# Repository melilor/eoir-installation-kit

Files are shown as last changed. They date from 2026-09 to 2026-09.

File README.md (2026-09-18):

# EO/IR Payload Installation Kit — Model-Based System Engineering Study



A model-based system engineering study of the **installation kit** that lets a light
helicopter (CS-27 class) or a tactical UAV carry a stabilised electro-optical / infrared
payload: the structural attachment, the electrical and avionic interfaces, the weight and
balance impact, the preservation of the payload field of view, and the compliance data an
EASA Part 21 Design Organisation Approval (DOA) holder works with.

The study is built as a **model**, not as a folder of documents. Requirements live in a
[Doorstop](https://doorstop.readthedocs.io) document, the architecture lives in YAML, every
requirement points at its source, and a validator in this repository fails the build when a
requirement has no source, no owning architecture element or no verification case — or when
a verification claims evidence that is not in the repository. The map of the whole study is
in [`docs/overview.md`](docs/overview.md).

```
$ python -m tools.traceability check
checked 38 requirements, 28 verification cases, 12 components: 0 errors, 12 warnings
```

The warnings are the discipline working: `ASM-OPEN` flags the evidence that rests on a
declared assumption that is still open (the payload data, the platform data, the harness
installation rules, the payload video link). They stay until the assumption is closed or the
limitation is accepted in writing.

## What this is / what this is not

| This repository is | This repository is not |
| --- | --- |
| a system engineering study of an installation kit | a design of the EO/IR sensor |
| a requirements, architecture and verification model with enforced traceability | a certification dossier |
| an application of CS-27, RTCA DO-160G and EASA Part 21 as a frame | an application of DO-178C, DO-331 or DO-254 |
| declared assumptions, marked as assumptions | measurements, test results or supplier data |
| a first published slice, with its gaps listed | a finished project |

The payload, the platform and the environment are **declared assumptions**, written in
[`model/assumptions.yaml`](model/assumptions.yaml) and referenced by the requirements that
depend on them. An assumption is an input the study needs, not a fact.

## Status

**Revision J — first published slice, 2026-09-18.** 38 requirements, 12 components, 28
verification cases, 15 declared assumptions, 13 documents, 93 layout checks, 16 mass checks, 3
clearance checks, 5 electrical checks, 44 load path checks, 46 qualification plan checks.
**Twenty-three cases are closed** at the level the evidence supports — thirteen `PASS` and ten
`LIMITATION` for what a model cannot demonstrate; the other 5 are `FUTURE` and point at the
ticket that will produce their evidence. The [technical report](docs/report.md) compiles the
study, its 34 classified limitations and the review of the package. The
[traceability matrix](docs/traceability.md) says this case by case, and it is generated from
the model, never written by hand.

## Quick start

```bash
pip install -r requirements.txt

doorstop --no-ref-check --no-level-check      # validate the requirements documents
python -m tools.traceability check            # validate the whole model
python -m tools.traceability report           # regenerate docs/traceability.md
python -m tools.diagram                       # regenerate docs/architecture.md
python -m tools.layout                        # run the layout checks, write evidence/layout/
python -m tools.compliance                    # regenerate docs/compliance-matrix.md
python -m tools.mass                          # run the mass and balance analysis
python -m tools.clearance                     # run the field of view and clearance analysis
python -m tools.power                         # run the electrical power budget and protection check
python -m tools.loads                         # run the load path and strength analysis
python -m tools.qualification                 # regenerate the environmental qualification plan
python -m tools.report                        # regenerate the technical report and run the review
python -m pytest                              # run the test suite
```

## Repository layout

```
model/
  requirements/          SYS001..SYS038 — system requirements (Doorstop)
  verification/          VER001..VER028 — verification cases, linked to their requirements
  architecture/          functions, components, interfaces, external boundary
  interfaces/            declared interface control data (payload, platform)
  assumptions.yaml       declared assumptions and interface data (ASM A-00x)
  evidence.yaml          one record per verification case: method, status, artifact, plan
  layout.yaml            the single source of truth for every dimension of the kit
  mass.yaml              component masses, stations and loadable configurations
  compliance.yaml        change classification and the document register
evidence/
  layout/                generated: checks.json, report.md, layout.svg, layout.dxf
  mass/                  generated: checks.json, report.md
  clearance/             generated: checks.json, report.md, sweep.svg
  power/                 generated: checks.json, report.md
  loads/                 generated: checks.json, report.md
  qualification/         generated: checks.json, report.md
  review/                generated: checks.json, report.md
tools/
  model.py               load the model parts
  rules.py               the validation rules, one identifier per failure
  analysis.py            the result structure shared by the analysis tools
  traceability.py        command line: check, report, report --check
  diagram.py             generate docs/architecture.md from the architecture model
  layout.py              run the layout checks and write the evidence
  mass.py                run the mass and balance analysis and write the evidence
  clearance.py           run the field of view analysis and write the evidence
  power.py               run the electrical analysis and write the evidence
  loads.py               run the load path and strength analysis and write the evidence
  qualification.py       generate the environmental qualification plan and check it
  report.py              generate the technical report and review the package
  compliance.py          generate the compliance matrix and the document register
tests/                   170 tests: one failing model per rule, plus the repository model
docs/
  overview.md            the map of the study: model, numbers, limits, next steps
  architecture.md        generated diagram and allocation tables
  traceability.md        generated matrix: requirement → architecture → verification → evidence
  compliance-matrix.md   generated: classification, compliance matrix, document register
  ica.md                 instructions for continued airworthiness (outline)
  method.md              how the model works and why the tools were chosen
  adr/                   decision records
```

## The model, in one picture

```
requirement (SYS) ──┬──> architecture element (CMP / FCT / IF) ──> allocation
                    │
                    └──> verification case (VER) ──> evidence record (method, status, artifact)
```

The rules that hold this together, each with a stable identifier in
[`tools/rules.py`](tools/rules.py):

| Rule | What it rejects |
| --- | --- |
| `REQ-SOURCE` | a requirement whose source is missing, malformed or an unknown assumption |
| `ARCH-ALLOC` | a requirement that no component owns |
| `ARCH-REQ` | an architecture element with no requirement, or pointing at one that does not exist |
| `ARCH-REALIZES` | a function no component realises, or a component that realises nothing |
| `VER-COVER` | a requirement with no verification case |
| `VER-EVIDENCE` | a verification case without an evidence record |
| `EVIDENCE-ARTIFACT` | a `PASS` or `WARN` claim whose artifact is not in the repository |
| `EVIDENCE-PLAN` | a `FUTURE` case with no ticket attached to it |
| `ASM-OPEN` | evidence produced against a declared assumption that is still open |
| `ASM-FILE` | an assumption pointing at declared interface data that is not in the repository |
| `COMPLIANCE-COVERAGE` | a requirement with no compliance document, or covered by more than one |
| `COMPLIANCE-REF` | a document covering an unknown requirement, an empty register entry, an unknown state or type, a duplicate id |
| `COMPLIANCE-FILE` | a document declared in the register whose file is not in the repository |
| `MASS-COVERAGE` | a component without a declared mass, or a mass entry for an unknown component |
| `CLASSIFICATION` | a change classification without criteria, with an unknown effect, or a major change without an approval route |

## Standards used as the frame

| Reference | Used for |
| --- | --- |
| 14 CFR Part 27 (CS-27 class) — 27.301/27.303/27.305, 27.23, 27.561, 27.1301/27.1309, 27.1316/27.1317, 27.1351–27.1367, 27.1529 | loads, factor of safety, strength, weight and balance, equipment installation, electrical systems, continued airworthiness |
| RTCA DO-160G — Sections 4, 6, 8, 14, 16, 20, 21 | environmental qualification of the installation |
| EASA Part 21 Subpart D (21.A.91/21.A.95/21.A.97) and 21.A.239 | change classification, approval route, design assurance |
| SAE ARP4754A | development process frame |
| ISO/IEC/IEEE 29148 | requirement quality criteria |
| ARINC 429 | payload control interface (declared) |

## Licence

Code: MIT (`LICENSE`). Documentation: CC BY 4.0 (`docs/LICENSE-CC-BY-4.0.md`).

## Author

Anthony Migliore — aerospace engineering graduate, Milan.
[LinkedIn](https://www.linkedin.com/in/miglioreanthony)

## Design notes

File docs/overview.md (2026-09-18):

# Study overview

The map of this repository: what the study is, how the model is built, what is verified and
what is not, and where the work goes next.

## What this study is

A model-based system engineering study of the **installation kit** that lets a light
helicopter (CS-27 class) or a tactical UAV carry a stabilised electro-optical / infrared
payload. The sensor is the input, not the subject: the subject is the structural attachment,
the electrical and avionic interfaces, the weight and balance impact, the preservation of
the field of view, and the compliance data frame an EASA Part 21 Design Organisation
Approval holder works with.

The study is built as a **model**, not as a folder of documents. Requirements live in a
Doorstop document, the architecture and the evidence live in YAML, and a validator in this
repository enforces the whole chain. If a requirement has no source, no owning component or
no verification case, the build is red.

**Status — revision J, 2026-09-18.** 38 requirements, 12 components, 28 verification cases,
15 declared assumptions, 93 layout checks, 16 mass checks, 3 clearance checks, 5 electrical
checks, 44 load path checks, 46 qualification plan checks, 13 documents in the compliance
register, 150 tests, CI green. **Twenty-three verification cases are closed** at the level the
evidence supports — thirteen `PASS` and ten `LIMITATION` for what a model cannot demonstrate;
the other 5 are `FUTURE` and each one names the ticket that will produce its evidence. Twelve
`ASM-OPEN` warnings flag the evidence that rests on a declared assumption that is still open. That is the honest state of the study and it is visible in
[the traceability matrix](traceability.md) and in the
[compliance matrix](compliance-matrix.md).

## The model, end to end

Every arrow below is a rule in `tools/rules.py`, checked in CI:

```
      ASSUMPTION A-00x                STANDARD (STD …)
      declared input                  cited clause
              \                        /
               \                      /
                ▼                    ▼
    ┌────────────────────────────────────────────────────────┐
    │ REQUIREMENT   SYS001 … SYS038                          │  REQ-SOURCE
    │ text + source + verifiable acceptance criterion        │  REQ-TEXT
    └───────────────────────┬────────────────────────────────┘
                            │
                            │  ARCH-ALLOC · ARCH-REQ · ARCH-REALIZES · ARCH-IFACE
                            ▼
    ┌────────────────────────────────────────────────────────┐
    │ ARCHITECTURE                                           │
    │ 9 functions (FCT) · 12 components (CMP)                │
    │ 9 interfaces (IF) · 6 external entities (EXT)          │
    └───────────────────────┬────────────────────────────────┘
                            │
                            │  VER-COVER · VER-LINK
                            ▼
    ┌────────────────────────────────────────────────────────┐
    │ VERIFICATION CASE   VER001 … VER028                    │
    │ method: analysis · review · inspection · test ·        │
    │         demonstration                                  │
    └───────────────────────┬────────────────────────────────┘
                            │
                            │  VER-EVIDENCE
                            ▼
    ┌────────────────────────────────────────────────────────┐
    │ EVIDENCE RECORD (one per case)                         │
    │ method · status · artifact · plan · note               │
    └───────────────────────┬────────────────────────────────┘
                            │
                            │  EVIDENCE-METHOD · EVIDENCE-STATUS
                            │  EVIDENCE-ARTIFACT · EVIDENCE-PLAN · EVIDENCE-NOTE
                            ▼
    ┌────────────────────────────────────────────────────────┐
    │ ARTIFACT IN THE REPOSITORY                             │
    │ 23 cases closed, 5 FUTURE — see the matrix             │
    └────────────────────────────────────────────────────────┘

    ASM-OPEN warns when evidence is produced against an assumption that is still open.
```

## Repository map

```
eoir-installation-kit/
├── README.md            what it is / what it is not, status, quick start
├── CONTEXT.md           glossary: kit, payload, requirement, evidence, assumption…
├── AGENTS.md            how to work in the repository (gate before every commit)
│
├── model/                        ← THE MODEL
│   ├── requirements/    SYS001–SYS038   (Doorstop: text + source)
│   ├── verification/    VER001–VER028   (Doorstop: method statement, linked to its SYS)
│   ├── architecture/    architecture.yaml: FCT, CMP, IF, EXT
│   ├── interfaces/      icd_payload.yaml · icd_platform.yaml (declared interface data)
│   ├── assumptions.yaml A-001–A-013, all OPEN with a rationale
│   ├── evidence.yaml    28 records: method, status, artifact, plan
│   ├── layout.yaml      the single source of truth for every dimension
│   ├── mass.yaml        component masses, stations and loadable configurations
│   └── compliance.yaml  change classification and the document register
│
├── evidence/
│   ├── layout/          GENERATED: checks.json · report.md · layout.svg · layout.dxf
│   ├── mass/            GENERATED: checks.json · report.md
│   ├── clearance/       GENERATED: checks.json · report.md · sweep.svg
│   ├── power/           GENERATED: checks.json · report.md
│   ├── loads/           GENERATED: checks.json · report.md
│   ├── qualification/   GENERATED: checks.json · report.md
│   └── review/          GENERATED: checks.json · report.md
│
├── tools/                        ← THE CHECK
│   ├── model.py         loads the model parts
│   ├── rules.py         15 rules, one stable identifier per failure
│   ├── analysis.py      the result structure shared by the analysis tools
│   ├── traceability.py  check · report · report --check
│   ├── diagram.py       generates docs/architecture.md (Mermaid + tables)
│   ├── layout.py        13 layout checks, writes evidence/layout/
│   ├── mass.py          4 mass and balance checks, writes evidence/mass/
│   ├── clearance.py     3 field of view checks, writes evidence/clearance/
│   ├── power.py         5 electrical checks, writes evidence/power/
│   ├── loads.py         44 load path checks, writes evidence/loads/
│   ├── qualification.py 46 plan checks, writes docs/qualification-plan.md
│   ├── report.py        33 review checks, writes docs/report.md
│   └── compliance.py    generates the compliance matrix and the document register
│
├── tests/               170 tests: one failing model per rule, plus the repository model
│
├── docs/
│   ├── overview.md      this file
│   ├── architecture.md  GENERATED diagram and allocation tables
│   ├── traceability.md  GENERATED matrix: requirement → architecture → verification → evidence
│   ├── method.md        how the model works and why these tools
│   ├── adr/0001-…       decision: the model is versioned text, not a graphical tool
│   └── agents/          tracker, triage labels and domain-doc conventions
│
├── .scratch/eoir-installation-kit/
│   ├── spec.md          specification: problem, stories, decisions, tests, out of scope
│   └── issues/01–12     tickets with their blocking edges
│
└── .github/workflows/ci.yml     Doorstop → check → matrix freshness → tests
```

## Numbers

| Item | Count |
| --- | --- |
| System requirements (`SYS`) | **38** |
| Standard citations / assumption citations in requirements | 43 / 17 |
| Declared assumptions | **13**, all `OPEN` |
| Functions / components / interfaces / external entities | 9 / **12** / 9 / 6 |
| Verification cases (`VER`) | **28** — `PASS` 13, `LIMITATION` 10, `FUTURE` 5 |
| Methods: analysis / review / inspection / test / demonstration | 8 / 11 / 5 / 2 / 2 |
| Layout checks | **93**, all passing |
| Mass checks | **16**, all passing |
| Clearance checks | **3**, all passing |
| Electrical checks | **5**, all passing |
| Load path checks | **44**, all passing |
| Qualification plan checks | **46**, all passing |
| Review checks | **33**, all passing |
| Qualification plan checks | **46**, all passing |
| Review checks | **33**, all passing |
| Compliance documents | **13** — every requirement covered exactly once |
| Validation rules | **15**, one identifier per failure |
| Tests | **170**, green |
| CI | green on every push |

## Requirements by class

| Class | Requirements | Main source |
| --- | --- | --- |
| Structure and loads | SYS001–SYS004 | 14 CFR 27.301/303/305/561 |
| Structural design rules | SYS024–SYS029 (fitting factor, material design values, fastener locking, protection of structure, inspection provisions, critical parts) | 14 CFR 27.602/607/609/611/613/625 |
| Mass and balance | SYS005–SYS007 | 14 CFR 27.23 + declared platform data |
| Installation, field of view, access | SYS008, SYS009, SYS018, SYS019, SYS028 | declared assumptions |
| Electrical and data | SYS010–SYS013, SYS030–SYS032 | 14 CFR 27.601 and 27.1351–27.1367 + declared interface data |
| Environment and EMC | SYS014–SYS017, SYS033–SYS035 | RTCA DO-160G Sections 4, 6, 8, 11–14, 16, 20, 21; 14 CFR 27.609/610/1309/1316/1317 |
| Certification and documentation | SYS020–SYS023, SYS036–SYS038 | EASA Part 21 21.A.239; 14 CFR 27.1529, 27.1583, 27.1589 |

Every clause number in the model was checked against the public text of the referenced
document before being cited.

## Architecture

| Component | Requirements | Realises |
| --- | --- | --- |
| CMP-01 Interface frame | 11 | attach, carry loads, preserve field of view |
| CMP-02 Platform attachment fittings | 9 | attach, carry loads |
| CMP-03 Payload interface plate | 7 | attach, preserve field of view |
| CMP-04 Power harness | 4 | supply power |
| CMP-05 Data harness | 4 | route data and video |
| CMP-06 Circuit protection assembly | 3 | protect power |
| CMP-07 Bonding straps and grounding hardware | 2 | bond the payload |
| CMP-08 Fastener and quick-release set | 3 | install and remove |
| CMP-09 Payload connector bracket and strain relief | 3 | route data, install and remove |
| CMP-10 Documentation and marking set | 8 | carry identity and compliance data |
| CMP-11 Environmental protection provisions | 7 | sustain the environment |
| CMP-12 Harness routing and protection provisions | 6 | route power and data, protect them |

The 9 interfaces connect the kit to the platform structure, the payload, the platform bus,
the mission system, the maintainer and the environment.

## What is verified, honestly

Twenty-three cases are closed at the level the evidence supports. Thirteen are `PASS`: the
layout checks (`VER008`, `VER019`, `VER021`, `VER023`), the compliance frame (`VER014`), the
mass and balance analysis (`VER003`, `VER004`), the field of view analysis (`VER005`), the
electrical power budget (`VER006`), the load path and strength analysis (`VER001`, `VER002`),
and the coverage and protection reviews of the qualification plan (`VER025`, `VER026`). Ten are
`LIMITATION` because a model, a plan or a review cannot demonstrate them: the 30-minute
maintainability target without an article (`VER013`), the ICA without intervals (`VER015`),
configuration control without an approved procedure (`VER027`), the flight manual supplement
without an aircraft (`VER028`), the protection coordination without the breaker trip curve
(`VER007`), the resonance separation — a single degree of freedom estimate cannot establish it
because its uncertainty is wider than the gap between the rotor harmonics (`VER011`) — and the
four items of the qualification plan that need a first article or a platform document: the
bonding resistance test (`VER009`), the review of the categories (`VER010`), the preservation
against the platform protection plan and its radio compatibility limits (`VER012`), and the
functional test of the data links (`VER016`). Every note states what the evidence does **not**
cover.

The other 5 cases are `FUTURE`, each pointing at the ticket that will produce the evidence. The
study demonstrates a method and a discipline, not a result. Twelve `ASM-OPEN` warnings mark the
places where evidence rests on a declared assumption that is still open.

## The gate

```bash
doorstop --no-ref-check --no-level-check      # validate the requirements documents
python -m tools.traceability check            # validate the whole model
python -m tools.traceability report           # regenerate the matrix
python -m tools.diagram                       # regenerate the architecture document
python -m tools.layout                        # run the layout checks, write the evidence
python -m tools.mass                          # run the mass analysis, write the evidence
python -m tools.clearance                     # run the field of view analysis, write the evidence
python -m tools.power                         # run the electrical analysis, write the evidence
python -m tools.loads                         # run the load path analysis, write the evidence
python -m tools.qualification                 # regenerate and check the qualification plan
python -m tools.report                        # regenerate the technical report and review the package
python -m tools.compliance                    # regenerate the compliance matrix
python -m pytest                              # run the test suite
```

The same five commands run in CI on every push. `report --check` and `diagram --check` fail
when the committed documents differ from the model, so the published artefacts cannot drift.

## What this demonstrates

| Question a reviewer asks | Where the answer is |
| --- | --- |
| Can this person structure a system model? | `model/`, the chain above, 38 requirements over 9 functions and 12 components |
| Can they manage requirements? | Doorstop, cited sources, declared assumptions, no requirement without a criterion |
| Do they understand verification? | 28 cases with a declared method and an honest state, plus rules that reject unsupported claims |
| Do they understand certification? | the change classification argued criterion by criterion, the document register, the ICA outline |
| Do they automate their own discipline? | `tools/rules.py` and the seven analysis tools, 169 tests, CI, generated evidence |
| Do they write documentation? | this file, `docs/method.md`, the ADR, the spec, the tickets |
| Do they know the standards frame? | CS-27/14 CFR Part 27, DO-160G, EASA Part 21, ARINC 429, ISO/IEC/IEEE 29148 |

## Limits, stated before anyone asks

- No physical verification: the fourteen closed cases are analyses and document reviews, and the
  installation target cannot be demonstrated without a first article.
- All 13 assumptions are `OPEN`: payload, platform and environment are declared inputs, not
  measurements.
- The layout is a two-view 2D envelope model, not 3D CAD: interference checking in three
  dimensions and the strength analysis are separate tickets.
- No graphical or behavioural model, no SysML semantics, no ReqIF/XMI exchange (ADR 0001).
- The sensor is not designed and will not be.
- DO-178C, DO-331 and DO-254 are framed, not applied.

## Where the work goes next

```
                 ┌────────────────────────────────┐
                 │ 01 FOUNDATION ✅               │
                 │ 02 REQUIREMENTS ✅             │
                 │ 03 ARCHITECTURE ✅             │
                 │ 08 GEOMETRY ✅                 │
                 │ 09 COMPLIANCE ✅               │
                 │ 04 MASS & CG ✅                │
                 │ 05 FOV & CLEARANCE ✅          │
                 │ 06 POWER & BONDING ✅          │
                 │ 07 LOAD PATH & STRENGTH ✅     │
                 │ 10 QUALIFICATION PLAN ✅       │
                 │ 11 REPORT + REVIEW ✅          │
                 └───────────────┬────────────────┘
                                 ▼
                                ▼
                     ┌─────────────────────┐
                     │ 12 PUBLICATION AND  │
                     │    APPLICATION      │
                     │    ALIGNMENT        │
                     └─────────────────────┘
```

Tickets live in `.scratch/eoir-installation-kit/issues/`, one file per ticket, each declaring
its blocking edges and its acceptance criteria. The spec behind them is
`.scratch/eoir-installation-kit/spec.md`.

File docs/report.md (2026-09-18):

<!-- Generated by tools/report.py — do not edit by hand. -->
<!-- Run: python -m tools.report -->

# EO/IR installation kit on a CS-27 class platform

**System study — requirements, architecture, analyses and verification evidence**

Revision A. 38 requirements, 28 verification cases, 12 components, 15 declared assumptions, 13 compliance documents, 170 tests.

This is the technical report of a system study: the installation of a stabilised electro-optical and infrared payload on a light helicopter of the CS-27 class and on a tactical unmanned aircraft. The study covers the mechanical interface, the electrical interface, the balance, the field of view, the strength, the resonance, the environmental qualification plan and the compliance frame. Everything it claims is produced by a tool in this repository, pointed at by an evidence file, and re-checked by the pipeline on every change. It is not a certification, not a design release and not a flight clearance, and the report says so wherever it matters.

## Contents

- R-01 Purpose and scope
- R-02 What this study is and what it is not
- R-03 Method
- R-04 The installation
- R-05 Results of the analyses
- R-06 Verification and evidence
- R-07 Assumptions
- R-08 Limitations
- R-09 Compliance and qualification
- R-10 Review
- R-11 What remains
- Annex: where the rest of the package is

## R-01 — Purpose and scope

The platform is a notional normal-category light helicopter in the CS-27 class, taken as four attachment provisions on the lower fuselage, a 28 VDC bus and a declared structural environment. The payload is a notional stabilised EO/IR unit of 45 kg with a declared envelope, mounting pattern, power demand, data interfaces and field of view. Both are declared inputs in model/interfaces/, not supplier data.

The product of the study is the installation kit: the interface frame, four attachment fittings, the payload interface plate, the power and data harnesses, the circuit protection assembly, the bonding hardware, the fastener set, the connector bracket, the documentation and marking set, the environmental protection provisions and the harness routing provisions. Twelve components, listed with their masses and their requirements in model/architecture/architecture.yaml.

The study stops at the payload interface. The payload itself, the platform structure, the mission system and the maintenance programme belong to somebody else, and the report says what the study assumes about each of them instead of inventing them.

## R-02 — What this study is and what it is not

It is a traceability and analysis exercise: every requirement has a source or a declared assumption, every requirement is allocated to a component, every requirement has a verification case, and every verification case has a record that says what the evidence shows and what it does not.

It is not a certification: the compliance frame reproduces the shape of a Part 21 change assessment and stays open where the platform or the authority owns the decision. It is not a design release: the materials, the joints and the environmental categories carry declared values that a certificate or a test has to confirm. It is not a flight clearance and not an airworthiness statement of any kind.

It is also not a model of everything. The analyses are deliberately small, closed-form and checkable by hand, and each one declares the idealisation it rests on. A study that hides its assumptions in an interface between tools is worth less than one that writes them down where a reader can challenge them.

## R-03 — Method

The model is text under version control: requirements as Doorstop items, architecture, interfaces, evidence, assumptions, compliance and the analysis inputs as YAML. No figure lives in a document: it lives in the model or in an evidence file, and the documents are generated. One declaration, one calculation is the rule that makes the difference: the payload mass is declared once in the interface file, and the mass analysis, the load analysis and the report all read it from there.

Every analysis is a tool that computes, writes an evidence file and can check that the committed evidence is still what it would produce now. The pipeline runs those checks on every change, together with the tests, so the repository cannot claim a state it no longer has.

Each finding names a check, a subject, a value, a limit and a margin. A check that fails names the violated constraint; a check that passes carries the margin it passed by. That is what makes the results chapter of this report readable as a table rather than as prose.

## R-04 — The installation

The kit hangs the payload below the fuselage on four fittings that mate with the platform provisions: 900 mm longitudinal spacing, 300 mm lateral, two M8 fasteners each. The attachment geometry is checked against those provisions, because the load path divides the reaction between the four points and a geometry that does not agree with the platform would silently invalidate the structural analysis.

The layout is a two-view two-dimensional model: rectangles, circles and orthogonal harness paths in millimetres, with the platform skin as a datum. It is not a three-dimensional CAD model, and that simplification is declared rather than hidden. Everything published about the geometry is generated from it: the checks, the figure in SVG and the drawing exchange file.

The kit weighs less than the declared target with a margin, sits within the certified centre of gravity range of the platform in every declared configuration, leaves the payload field of view clear, and moves less under limit load than the clearance it has left. Those four statements are the results of four analyses, and each one is a table in the next chapter.

## R-05 — Results of the analyses

The analyses are listed below with the check count, the finding that comes closest to its limit and the file that holds every number. The governing finding is the one with the smallest margin relative to its limit, which is not the same as the most important one: a small margin on a declared capability matters less than a large one on a design rule that has not been confirmed.

### The numbers a reader should see first

| Number | Value | Against | Read from |
| --- | --- | --- | --- |
| Installed kit mass | 13.6 kg | the 15.0 kg target | `evidence/mass/checks.json` → `kit_mass_kg` |
| Worst platform centre of gravity | 2987.03 mm | the forward limit of 2900 mm | `evidence/mass/checks.json` → `configurations[0].cg_mm_aft_of_datum` |
| Governing fitting reaction | 763.0 N | 25 000 N per hard point | `evidence/loads/checks.json` → `governing_case_by_check.LOADS-HARD-POINT.reaction_n` |
| Relative movement under limit load | 2.18 mm | 5.0 mm available at the tightest direction | `evidence/loads/checks.json` → `deflection.value_mm` |
| First mode estimate at the softest idealisation | 21.88 Hz | the lowest rotor band | `evidence/loads/checks.json` → `resonance.estimate_low_hz` |
| First mode estimate at the stiffest idealisation | 43.29 Hz | the tail rotor 1/rev band | `evidence/loads/checks.json` → `resonance.estimate_high_hz` |
| Continuous voltage drop | 0.18 V | the 2 % limit of 0.560 V | `evidence/power/checks.json` → `circuits[0].continuous_drop_v` |
| Peak voltage drop | 0.48 V | the 4 % limit of 1.120 V | `evidence/power/checks.json` → `circuits[0].peak_drop_v` |
| Zone selections carrying a category | 6 selections | the zone selections where a section applies | `evidence/qualification/checks.json` → `selected_categories` |
| Zone selections open on a platform input | 31 selections | the zone selections where a section applies | `evidence/qualification/checks.json` → `open_categories` |
| Section entries closed by analysis or inspection | 3 entries | the section entries | `evidence/qualification/checks.json` → `status_counts.ASSESSED` |

### The finding that comes closest to its limit, per analysis

| Analysis | Checks | Failed | Closest to its limit | Value | Limit | Margin | Artifact |
| --- | --- | --- | --- | --- | --- | --- | --- |
| layout | 93 | 0 | ATTACHMENT-PATTERN on fitting-centres | 4.0 | 4.0 | 0.0 | `evidence/layout/checks.json` |
| mass | 16 | 0 | MASS-PAYLOAD on CFG-01 | 150.0 | 150.0 | 0.0 | `evidence/mass/checks.json` |
| clearance | 3 | 0 | FOV-OBSTRUCTION on payload-installed | 0.0 | 0.0 | 0.0 | `evidence/clearance/checks.json` |
| power | 5 | 0 | POWER-BREAKER on CMP-06 | 20.0 | 17.857142857142858 | 2.143 | `evidence/power/checks.json` |
| loads | 44 | 0 | LOADS-FACTOR-OF-SAFETY on LC-EML-AFT | 1.0 | 1.0 | 0.0 | `evidence/loads/checks.json` |
| qualification | 46 | 0 | QUAL-COMPONENT-ZONE on CMP-01 | 1.0 | 1.0 | 0.0 | `evidence/qualification/checks.json` |

Every number in that table is read from the artifact in the last column, which is generated by the tool of the same name in `tools/`. The full finding sets, with one row per check, are in `evidence/<analysis>/report.md`.

## R-06 — Verification and evidence

Twenty-eight verification cases cover the thirty-eight requirements. Each case names its method, and its record names the artifact that carries the result. A case with a passed status must have an artifact that exists; a case that is still to come must name the ticket that will produce it; a case the study cannot close must say what it does not cover. Those rules are enforced by the model validator, not by discipline.

The evidence is deliberately mixed. Where an analysis can answer, it answers. Where the answer needs a physical article or a platform document, the case says so and stays open. A study of this size that reported everything as verified would be lying about at least half of it.

| Case | Method | Status | Artifact or plan |
| --- | --- | --- | --- |
| VER001 | analysis | PASS | `evidence/loads/checks.json` |
| VER002 | analysis | PASS | `evidence/loads/checks.json` |
| VER003 | analysis | PASS | `evidence/mass/checks.json` |
| VER004 | analysis | PASS | `evidence/mass/checks.json` |
| VER005 | analysis | PASS | `evidence/clearance/checks.json` |
| VER006 | analysis | PASS | `evidence/power/checks.json` |
| VER007 | inspection | LIMITATION | `evidence/power/checks.json` |
| VER008 | inspection | PASS | `evidence/layout/checks.json` |
| VER009 | test | LIMITATION | `docs/qualification-plan.md` |
| VER010 | review | LIMITATION | `docs/qualification-plan.md` |
| VER011 | analysis | LIMITATION | `evidence/loads/checks.json` |
| VER012 | review | LIMITATION | `docs/qualification-plan.md` |
| VER013 | demonstration | LIMITATION | `evidence/layout/checks.json` |
| VER014 | review | PASS | `docs/compliance-matrix.md` |
| VER015 | review | LIMITATION | `docs/ica.md` |
| VER016 | test | LIMITATION | `docs/qualification-plan.md` |
| VER017 | analysis | FUTURE | `plan: issues/07-analysis-load-path-and-strength` |
| VER018 | review | FUTURE | `plan: issues/07-analysis-load-path-and-strength` |
| VER019 | inspection | PASS | `evidence/layout/checks.json` |
| VER020 | review | FUTURE | `plan: issues/07-analysis-load-path-and-strength` |
| VER021 | demonstration | PASS | `evidence/layout/checks.json` |
| VER022 | review | FUTURE | `plan: issues/07-analysis-load-path-and-strength` |
| VER023 | inspection | PASS | `evidence/layout/checks.json` |
| VER024 | inspection | FUTURE | `plan: issues/06-analysis-power-and-bonding` |
| VER025 | review | PASS | `docs/qualification-plan.md` |
| VER026 | review | PASS | `docs/qualification-plan.md` |
| VER027 | review | LIMITATION | `docs/compliance-matrix.md` |
| VER028 | review | LIMITATION | `docs/compliance-matrix.md` |

13 cases are closed with evidence, 10 are limited and 5 are still to come. The note of each case, in `model/evidence.yaml`, says what the evidence does not cover.

## R-07 — Assumptions

Every input the study needs and cannot derive is declared with a rationale, a status and the file it lives in. An open assumption that carries evidence is reported as a warning by the validator, so the reader can see which results rest on a figure nobody has confirmed yet. The register below lists them with the source that would close each one.

| Assumption | Statement | Status | Data file |
| --- | --- | --- | --- |
| A-001 | The payload is a stabilised electro-optical / infrared unit with a mass not exceeding 45 kg, whose centre of gravity lies within 150 mm of the payload mounting … | OPEN | `model/interfaces/icd_payload.yaml` |
| A-002 | The platform is a normal-category light helicopter in the CS-27 class with a maximum take-off mass of 2 250 kg, an empty mass of 1 350 kg and a certified CG ran… | OPEN | `model/interfaces/icd_platform.yaml` |
| A-003 | The payload field of view is continuous in azimuth and spans -120 deg to +30 deg in elevation, measured from the payload mounting datum. | OPEN | `model/interfaces/icd_payload.yaml` |
| A-004 | The installed kit, excluding the payload, is not to exceed 15 kg. | OPEN | `—` |
| A-005 | The minimum clearance between the payload swept volume and the platform structure is 25 mm. | OPEN | `—` |
| A-006 | The payload draws 28 VDC electrical power from the platform bus, 150 W continuous and 400 W peak. | OPEN | `model/interfaces/icd_payload.yaml` |
| A-007 | The payload control interface is ARINC 429 and the video output is a digital video link carried on a dedicated harness to the mission system panel. | OPEN | `model/interfaces/icd_payload.yaml` |
| A-008 | The bonding resistance between the payload and the platform structure shall not exceed 2.5 mΩ. | OPEN | `model/interfaces/icd_platform.yaml` |
| A-009 | The DO-160G sections and categories applicable to the installation are selected by installation zone in the qualification plan and are not yet selected. | OPEN | `—` |
| A-010 | The main rotor operates between 350 and 400 rpm and the tail rotor between 2 000 and 2 400 rpm over the operating range, with three main rotor blades and two ta… | OPEN | `model/interfaces/icd_platform.yaml` |
| A-011 | The payload can be installed or removed by two maintainers using standard tools in 30 minutes or less, and the attachment fittings and the payload connector can… | OPEN | `—` |
| A-012 | Harness routing follows declared rules: minimum bend radius of five times the cable outside diameter, clamp spacing not exceeding 200 mm, a minimum clearance of… | OPEN | `—` |
| A-013 | Fastener holes in the kit fittings keep an edge distance of at least twice the fastener diameter and a pitch of at least three times the diameter, and the fitti… | OPEN | `model/layout.yaml` |
| A-014 | The kit frame is built from two 40 x 40 x 3 mm square tubes in 6082-T6 and the fittings from 10 mm plate in the same alloy, fastened with M8 A4-80 fasteners. Th… | OPEN | `model/loads.yaml` |
| A-015 | The relative movement between the payload and the platform structure under the load cases of this study is limited by the clearance the field of view analysis a… | OPEN | `model/loads.yaml` |

## R-08 — Limitations

A limitation is a statement the study cannot make, with the reason and what would close it. They come from three places: the verification cases the evidence cannot close, the open items the analyses recorded, and the assumptions still open. Each one is classified: an input is missing, the method cannot show it, it needs a physical article, it needs the platform or the authority, or it is a limitation of the review itself.

No check was relaxed to make this list shorter. Where an analysis found a problem — the antenna that sat inside the field of view, the attachment geometry that did not match the platform provisions, the inrush above the breaker rating, the resonance estimate inside the rotor bands — the problem is in this register or it was fixed in the design, and the report says which.

| Limitation | Class | What it is | What closes it |
| --- | --- | --- | --- |
| A-001 (open assumption) | INPUT | Payload mass and CG envelope: The payload is a stabilised electro-optical / infrared unit with a mass not exceeding 45 kg, whose centre of gravity lies within 150 mm of the payload mounting datum in all operating configu… | the payload supplier data sheet |
| A-002 (open assumption) | INPUT | Platform class and mass and balance data: The platform is a normal-category light helicopter in the CS-27 class with a maximum take-off mass of 2 250 kg, an empty mass of 1 350 kg and a certified CG range of 2 900 to 3 1… | the platform type data |
| A-003 (open assumption) | INPUT | Payload field of view: The payload field of view is continuous in azimuth and spans -120 deg to +30 deg in elevation, measured from the payload mounting datum. | the payload supplier data sheet |
| A-004 (open assumption) | INPUT | Kit mass target: The installed kit, excluding the payload, is not to exceed 15 kg. | the platform mass budget |
| A-005 (open assumption) | AUTHORITY | Minimum clearance: The minimum clearance between the payload swept volume and the platform structure is 25 mm. | the platform installation standard confirms the clearance rule |
| A-006 (open assumption) | INPUT | Payload electrical demand: The payload draws 28 VDC electrical power from the platform bus, 150 W continuous and 400 W peak. | the payload supplier data sheet |
| A-007 (open assumption) | INPUT | Payload data interfaces: The payload control interface is ARINC 429 and the video output is a digital video link carried on a dedicated harness to the mission system panel. | the payload supplier data sheet |
| A-008 (open assumption) | AUTHORITY | Bonding resistance: The bonding resistance between the payload and the platform structure shall not exceed 2.5 mΩ. | the platform bonding and grounding standard |
| A-009 (open assumption) | AUTHORITY | Environmental qualification categories: The DO-160G sections and categories applicable to the installation are selected by installation zone in the qualification plan and are not yet selected. | the joint category decision with the platform |
| A-010 (open assumption) | INPUT | Rotor excitation frequencies: The main rotor operates between 350 and 400 rpm and the tail rotor between 2 000 and 2 400 rpm over the operating range, with three main rotor blades and two tail rotor blades. The excitatio… | the platform type data |
| A-011 (open assumption) | AUTHORITY | Maintainability targets: The payload can be installed or removed by two maintainers using standard tools in 30 minutes or less, and the attachment fittings and the payload connector can be inspected without removing the … | the platform maintenance requirements |
| A-012 (open assumption) | AUTHORITY | Harness installation rules: Harness routing follows declared rules: minimum bend radius of five times the cable outside diameter, clamp spacing not exceeding 200 mm, a minimum clearance of 50 mm from surfaces above 100 d… | the platform installation standard confirms the harness rules |
| A-013 (open assumption) | AUTHORITY | Joint design rules: Fastener holes in the kit fittings keep an edge distance of at least twice the fastener diameter and a pitch of at least three times the diameter, and the fitting material thickness around a hole is a… | the platform structural repair and installation standard |
| A-014 (open assumption) | INPUT | Structural idealisation and material allowables: The kit frame is built from two 40 x 40 x 3 mm square tubes in 6082-T6 and the fittings from 10 mm plate in the same alloy, fastened with M8 A4-80 fasteners. The strength … | the material certificate and the fastener specification |
| A-015 (open assumption) | INPUT | Available relative movement at the tightest field of view direction: The relative movement between the payload and the platform structure under the load cases of this study is limited by the clearance the field of view a… | the design review confirms the acceptance criterion for the movement |
| OI-01 (open item) | AUTHORITY | an open item of an analysis, recorded in the model file that holds it | the platform confirms which crash factors apply to a belly installation |
| OI-02 (open item) | METHOD | an open item of an analysis, recorded in the model file that holds it | a modal analysis or a test that measures the modes and the damping |
| OI-03 (open item) | METHOD | an open item of an analysis, recorded in the model file that holds it | a finite element model of the plate |
| OI-04 (open item) | INPUT | an open item of an analysis, recorded in the model file that holds it | the breaker trip curve |
| OI-05 (open item) | AUTHORITY | an open item of an analysis, recorded in the model file that holds it | the platform electrical load analysis document |
| QI-01 (open item) | AUTHORITY | an open item of an analysis, recorded in the model file that holds it | the platform declares its radio compatibility limits |
| QI-02 (open item) | AUTHORITY | an open item of an analysis, recorded in the model file that holds it | the platform compartment map and the joint decision on the categories |
| QI-03 (open item) | INPUT | an open item of an analysis, recorded in the model file that holds it | the kit gets an environmental specification of its own |
| REVIEW (open item) | INDEPENDENCE | an open item of an analysis, recorded in the model file that holds it | an external engineer reviews the package against the model |
| VER007 (limitation case) | INPUT | The protection is coordinated on the steady and peak demand, and the value to enter in the platform electrical load analysis is computed and identified. Two items are open and recorded in model/power.yaml: the declared 2… | the breaker trip curve from the equipment supplier |
| VER009 (limitation case) | ARTICLE | The bonding path is declared (CMP-07 and the bonding provisions of PP-01) and the test is planned on the first article with the rest of the campaign, but no article exists in this study, so the resistance is not measured… | the bonding resistance test on the first article (TP-002) |
| VER010 (limitation case) | AUTHORITY | DO-160G section and category selection per installation zone. | the platform compartment map and the standard itself |
| VER011 (limitation case) | METHOD | The excitation bands are computed from the declared rotor data and the separation criterion is applied to them, but the separation is not demonstrated. The single degree of freedom estimate of the installation is 21.9 to… | a modal analysis or a ground vibration test |
| VER012 (limitation case) | AUTHORITY | Preservation of the platform lightning and HIRF protection. | the platform protection plan and the radio compatibility limits |
| VER013 (limitation case) | ARTICLE | The layout demonstrates the free removal corridor and the inspection access. The 30-minute installation and removal target with two maintainers cannot be demonstrated without a first article; only the geometric condition… | the install and remove demonstration on the first article |
| VER015 (limitation case) | AUTHORITY | The instructions for continued airworthiness are outlined against 14 CFR 27.1529 and Appendix A: applicability, servicing, scheduled inspections, wear items, structural repair, troubleshooting and parts list. The interva… | the platform maintenance review board intervals |
| VER016 (limitation case) | ARTICLE | ARINC 429 and video interface functional test on the first article. | the functional test on the first article (FT-01) |
| VER027 (limitation case) | AUTHORITY | The document register assigns a revision to every deliverable and the drawing documents carry part identification (DWG-001, DWG-002). A configuration control procedure approved under a design organisation approval does n… | the approved configuration control procedure of the design organisation |
| VER028 (limitation case) | ARTICLE | The loading information document is planned (FMS-001) and the weight and balance data are inputs of the mass analysis, but no flight manual supplement exists yet: it is produced with the platform operator. | an aircraft that exists and a flight manual to supplement |

Classes: **INPUT** — a declared input is missing or unconfirmed; **METHOD** — the method used cannot show it; **ARTICLE** — it needs a physical article; **AUTHORITY** — it needs the platform, the installer or the competent authority; **INDEPENDENCE** — the limitation of the review itself.

## R-09 — Compliance and qualification

The compliance frame follows the shape of a Part 21 change to a type design: the change classification is argued against nine criteria of appreciable effect and stays open until the design organisation confirms it, and thirteen documents cover the requirements exactly once each. The compliance matrix is generated and checked, so the coverage cannot rot quietly.

The environmental qualification plan assigns every component to an installation zone, selects the DO-160G sections that reach each zone and states, for every section, the category or the input the category waits for, the method, the article and what cannot be shown without one. The standard is not part of this repository, so no category is invented: a category is written down only where a declared input of the study and a public statement about the standard fix it.

| Document | Type | State | Requirements covered |
| --- | --- | --- | --- |
| DWG-001 Installation layout drawing | drawing | DRAFT | 7 |
| DWG-002 Harness routing and installation drawing | drawing | DRAFT | 3 |
| AN-001 Structural analysis report | analysis | PLANNED | 6 |
| AN-002 Mass and balance report | analysis | PLANNED | 2 |
| AN-003 Field of view and clearance analysis | analysis | PLANNED | 2 |
| AN-004 Electrical load and power budget | analysis | PLANNED | 3 |
| AN-005 Resonance and vibration assessment | analysis | PLANNED | 1 |
| AN-006 Materials and corrosion protection scheme | analysis | PLANNED | 1 |
| TP-001 Environmental qualification plan and reports | test | DRAFT | 6 |
| TP-002 Bonding resistance test report | test | PLANNED | 1 |
| ICA-001 Instructions for continued airworthiness | ica | OUTLINE | 1 |
| CS-001 Compliance checklist and change classification record | checklist | GENERATED | 4 |
| FMS-001 Flight manual supplement and loading information | manual | PLANNED | 1 |

The coverage is exact: every requirement is covered by exactly one document, and the model validator refuses the repository otherwise. The classification of the change, the approval route and the privileges are in `model/compliance.yaml`.

## R-10 — Review

The review was executed against the requirement and evidence model, not against this prose: a program reads the model files and the evidence files and answers a list of review questions with checks that fail visibly. That is what makes it reproducible, and it is also its limit.

Kind: **mechanical and reproducible**. Run by: tools/report.py, run by the pipeline on every change and by the author. Independent: **no**.

What the review asks:

- Every analysis the report quotes has an evidence file that exists and reports no failure.
- Every number the repository documents quote matches the model and the evidence.
- Every limitation of the model is classified, and every classification names a real limitation.
- Every verification case that needs a future ticket points at a ticket file that exists.
- Every verification case with a passed status has an artifact that exists.
- {'No case in the register carries the warning status': 'a warning is not promoted to a pass.'}

What it found: nothing that is not already in the limitation register, and the register is checked against the model in both directions, so a limitation cannot be dropped from it and a classification cannot survive the limitation it described.

What it cannot do:

The study has one author, so this review is not independent in the sense a certification programme means. It is mechanical: every question is answered by a check that reads the model and the evidence files and fails in public, which is more than a rereading and less than a second engineer. An external review is a condition of using this material for anything other than a portfolio.

## R-11 — What remains

The study has one ticket left: publishing the package and aligning the application material with what the repository actually contains. Beyond that, the list in the limitations register is the work programme: the inputs a platform has to supply, the articles a campaign needs, and the two analyses — a modal survey and a detailed finite element model — that the closed-form idealisations cannot replace.

## Annex

- `docs/traceability.md` — the matrix: requirement, allocation, verification case, evidence state.
- `docs/compliance-matrix.md` — the requirements against the compliance documents.
- `docs/architecture.md` — the functions, components and interfaces, with the allocation.
- `docs/qualification-plan.md` — the environmental qualification plan.
- `evidence/` — every artifact the report quotes, generated by the tool named in each file header.

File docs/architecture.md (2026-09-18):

<!-- Generated by tools/diagram.py — do not edit by hand. -->
<!-- Run: python -m tools.diagram -->

# Architecture

Generated from the architecture model and the requirements: the functions, the components that realise them, the interfaces and the external boundary.

## Diagram

```mermaid
graph LR
    EXT_PLATFORM(["Platform structure"])
    EXT_PAYLOAD(["EO/IR payload"])
    EXT_PLATFORM_BUS(["Platform 28 VDC bus"])
    EXT_MISSION_SYSTEM(["Mission system"])
    EXT_MAINTAINER(["Maintenance crew"])
    EXT_ENVIRONMENT(["Environment"])
    CMP_01["CMP-01<br/>Interface frame<br/>11 requirements"]
    CMP_02["CMP-02<br/>Platform attachment fittings<br/>9 requirements"]
    CMP_03["CMP-03<br/>Payload interface plate<br/>7 requirements"]
    CMP_04["CMP-04<br/>Power harness<br/>4 requirements"]
    CMP_05["CMP-05<br/>Data harness<br/>4 requirements"]
    CMP_06["CMP-06<br/>Circuit protection assembly<br/>3 requirements"]
    CMP_07["CMP-07<br/>Bonding straps and grounding hardware<br/>2 requirements"]
    CMP_08["CMP-08<br/>Fastener and quick-release set<br/>3 requirements"]
    CMP_09["CMP-09<br/>Payload connector bracket and strain relief<br/>3 requirements"]
    CMP_10["CMP-10<br/>Documentation and marking set<br/>8 requirements"]
    CMP_11["CMP-11<br/>Environmental protection provisions<br/>7 requirements"]
    CMP_12["CMP-12<br/>Harness routing and protection provisions<br/>6 requirements"]
    CMP_02 -->|"IF-01: Platform to kit mechanical attachment"| EXT_PLATFORM
    CMP_03 -->|"IF-02: Kit to payload mechanical attachment"| EXT_PAYLOAD
    CMP_06 -->|"IF-03: Platform bus to power harness"| EXT_PLATFORM_BUS
    CMP_05 -->|"IF-04: Payload control link (ARINC 429)"| EXT_MISSION_SYSTEM
    CMP_05 -->|"IF-05: Payload video link"| EXT_MISSION_SYSTEM
    CMP_07 -->|"IF-06: Bonding path to platform structure"| EXT_PLATFORM
    CMP_08 -->|"IF-07: Installation and removal access"| EXT_MAINTAINER
    CMP_11 -->|"IF-08: Environmental exposure of the installation"| EXT_ENVIRONMENT
    CMP_12 -->|"IF-09: Harness routing and protection through the installation"| EXT_ENVIRONMENT

    class CMP_01 component
    class CMP_02 component
    class CMP_03 component
    class CMP_04 component
    class CMP_05 component
    class CMP_06 component
    class CMP_07 component
    class CMP_08 component
    class CMP_09 component
    class CMP_10 component
    class CMP_11 component
    class CMP_12 component
    classDef component fill:#eef,stroke:#446
```

## Functions

| Function | Name | Requirements | Realised by |
| --- | --- | --- | --- |
| FCT-01 | Attach the payload to the platform | SYS001<br/>SYS006<br/>SYS009 | CMP-01, CMP-02, CMP-03 |
| FCT-02 | Transfer payload loads to the platform primary structure | SYS002<br/>SYS003<br/>SYS004<br/>SYS005<br/>SYS007<br/>SYS024<br/>SYS025<br/>SYS026<br/>SYS028<br/>SYS029 | CMP-01, CMP-02 |
| FCT-03 | Supply and protect payload electrical power | SYS010<br/>SYS011<br/>SYS032 | CMP-04, CMP-06, CMP-12 |
| FCT-04 | Route payload control and video data | SYS012<br/>SYS030<br/>SYS031 | CMP-05, CMP-09, CMP-12 |
| FCT-05 | Bond the payload to the platform ground reference | SYS013 | CMP-07 |
| FCT-06 | Allow installation, removal and inspection | SYS018<br/>SYS019<br/>SYS028<br/>SYS031 | CMP-08, CMP-09, CMP-12 |
| FCT-07 | Preserve payload field of view and clearances | SYS008<br/>SYS009 | CMP-01, CMP-03 |
| FCT-08 | Carry installation identity and compliance data | SYS020<br/>SYS021<br/>SYS022<br/>SYS023<br/>SYS036<br/>SYS037<br/>SYS038 | CMP-10 |
| FCT-09 | Sustain the environmental and electromagnetic environment | SYS014<br/>SYS015<br/>SYS016<br/>SYS017<br/>SYS027<br/>SYS033<br/>SYS034<br/>SYS035 | CMP-11, CMP-12 |

## Components

| Component | Name | Realises | Requirements |
| --- | --- | --- | --- |
| CMP-01 | Interface frame | FCT-01, FCT-02, FCT-07 | SYS001<br/>SYS002<br/>SYS003<br/>SYS005<br/>SYS007<br/>SYS008<br/>SYS009<br/>SYS024<br/>SYS025<br/>SYS027<br/>SYS028 |
| CMP-02 | Platform attachment fittings | FCT-01, FCT-02 | SYS001<br/>SYS002<br/>SYS003<br/>SYS004<br/>SYS024<br/>SYS026<br/>SYS027<br/>SYS028<br/>SYS029 |
| CMP-03 | Payload interface plate | FCT-01, FCT-07 | SYS001<br/>SYS006<br/>SYS008<br/>SYS009<br/>SYS024<br/>SYS026<br/>SYS029 |
| CMP-04 | Power harness | FCT-03 | SYS010<br/>SYS011<br/>SYS030<br/>SYS033 |
| CMP-05 | Data harness | FCT-04 | SYS012<br/>SYS016<br/>SYS030<br/>SYS035 |
| CMP-06 | Circuit protection assembly | FCT-03 | SYS010<br/>SYS011<br/>SYS032 |
| CMP-07 | Bonding straps and grounding hardware | FCT-05 | SYS013<br/>SYS035 |
| CMP-08 | Fastener and quick-release set | FCT-06 | SYS018<br/>SYS026<br/>SYS027 |
| CMP-09 | Payload connector bracket and strain relief | FCT-04, FCT-06 | SYS018<br/>SYS019<br/>SYS031 |
| CMP-10 | Documentation and marking set | FCT-08 | SYS007<br/>SYS020<br/>SYS021<br/>SYS022<br/>SYS023<br/>SYS036<br/>SYS037<br/>SYS038 |
| CMP-11 | Environmental protection provisions | FCT-09 | SYS014<br/>SYS015<br/>SYS016<br/>SYS017<br/>SYS027<br/>SYS033<br/>SYS034 |
| CMP-12 | Harness routing and protection provisions | FCT-03, FCT-04, FCT-06, FCT-09 | SYS030<br/>SYS031<br/>SYS033<br/>SYS034<br/>SYS035<br/>SYS038 |

## Interfaces

| Interface | Name | From | To | Requirements |
| --- | --- | --- | --- | --- |
| IF-01 | Platform to kit mechanical attachment | CMP-02 | EXT-PLATFORM | SYS001<br/>SYS004 |
| IF-02 | Kit to payload mechanical attachment | CMP-03 | EXT-PAYLOAD | SYS001<br/>SYS006 |
| IF-03 | Platform bus to power harness | CMP-06 | EXT-PLATFORM-BUS | SYS010<br/>SYS011 |
| IF-04 | Payload control link (ARINC 429) | CMP-05 | EXT-MISSION-SYSTEM | SYS012 |
| IF-05 | Payload video link | CMP-05 | EXT-MISSION-SYSTEM | SYS012 |
| IF-06 | Bonding path to platform structure | CMP-07 | EXT-PLATFORM | SYS013 |
| IF-07 | Installation and removal access | CMP-08 | EXT-MAINTAINER | SYS018<br/>SYS019 |
| IF-08 | Environmental exposure of the installation | CMP-11 | EXT-ENVIRONMENT | SYS014<br/>SYS015<br/>SYS016<br/>SYS017<br/>SYS033<br/>SYS034 |
| IF-09 | Harness routing and protection through the installation | CMP-12 | EXT-ENVIRONMENT | SYS030<br/>SYS031<br/>SYS035 |

## External boundary

| External | Meaning |
| --- | --- |
| EXT-PLATFORM | Platform structure |
| EXT-PAYLOAD | EO/IR payload |
| EXT-PLATFORM-BUS | Platform 28 VDC bus |
| EXT-MISSION-SYSTEM | Mission system |
| EXT-MAINTAINER | Maintenance crew |
| EXT-ENVIRONMENT | Environment |

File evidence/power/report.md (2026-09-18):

<!-- Generated by tools/power.py — do not edit by hand. -->
<!-- Run: python -m tools.power -->

# Electrical power budget and protection

Revision A, bus 28 VDC. 5 checks, 5 passed, 0 failed.

## Inputs

- Payload demand: 150 W continuous, 400 W peak, 25 A inrush
- Platform bus: 3000 W capacity, 2100 W already loaded
- Protection: circuit breaker in the platform distribution panel rated 20 A (`CMP-06`), trip curve: not available in this study

## Circuits

| Harness | Component | Conductor (mm2) | Length (m) | Continuous (A) | Peak (A) | Drop continuous (V) | Drop peak (V) | Ampacity (A) | Loss (W) |
| --- | --- | --- | --- | --- | --- | --- | --- | --- | --- |
| HR-01 | CMP-04 | 2.5 | 2.4 | 5.36 | 14.29 | 0.180 | 0.480 | 20 | 0.96 |

## Checks

| Check | Subject | Status | Value | Limit | Margin |
| --- | --- | --- | --- | --- | --- |
| POWER-AMPACITY | HR-01 | PASS | 5.36 | 20 | +14.64 |
| POWER-BREAKER | CMP-06 | PASS | 20.00 | 17.8571 | +2.14 |
| POWER-BUS | platform | PASS | 2250.96 | 3000 | +749.04 |
| POWER-CONTINUOUS | HR-01 | PASS | 0.18 | 0.56 | +0.38 |
| POWER-PEAK | HR-01 | PASS | 0.48 | 1.12 | +0.64 |

## Open items

- {'id': 'OI-04', 'title': 'The payload inrush is above the breaker rating and the trip curve is not available', 'detail': 'The declared inrush of 25 A exceeds the 20 A breaker rating, and the trip curve of the device is not part of the declared data. The steady and peak demand are coordinated and recorded above; the transient cannot be closed until the curve is available, or until a higher rating with a larger conductor is chosen deliberately.'}
- {'id': 'OI-05', 'title': 'The entry in the platform electrical load analysis belongs to the platform document', 'detail': 'The analysis computes the value to enter, 2251 W against a 3000 W bus, and identifies the circuit. Recording it in the platform load analysis is an action on the platform documentation, not on this study.'}

The inrush against the breaker rating is the reason the protection coordination carries a LIMITATION in the evidence register instead of a PASS: the analysis cannot close it without the trip curve.

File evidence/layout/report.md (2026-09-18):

<!-- Generated by tools/layout.py — do not edit by hand. -->
<!-- Run: python -m tools.layout -->

# Layout checks

Revision A, units mm. 93 checks, 93 passed, 0 failed.

| Check | Subject | Status | Value | Limit | Margin |
| --- | --- | --- | --- | --- | --- |
| ATTACHMENT-PATTERN | fitting-centres | PASS | 4.00 | 4 | +0.00 |
| ATTACHMENT-SPACING | lateral | PASS | 300.00 | 300 | +0.00 |
| ATTACHMENT-SPACING | longitudinal | PASS | 900.00 | 900 | +0.00 |
| BEND-RADIUS | HR-01 | PASS | 80.00 | 70 | +10.00 |
| BEND-RADIUS | HR-02 | PASS | 60.00 | 50 | +10.00 |
| CLAMP-ON-PATH | HR-01:clamp1 | PASS | 0.00 | 1 | +1.00 |
| CLAMP-ON-PATH | HR-01:clamp2 | PASS | 0.00 | 1 | +1.00 |
| CLAMP-ON-PATH | HR-01:clamp3 | PASS | 0.00 | 1 | +1.00 |
| CLAMP-ON-PATH | HR-01:clamp4 | PASS | 0.00 | 1 | +1.00 |
| CLAMP-ON-PATH | HR-01:clamp5 | PASS | 0.00 | 1 | +1.00 |
| CLAMP-ON-PATH | HR-01:clamp6 | PASS | 0.00 | 1 | +1.00 |
| CLAMP-ON-PATH | HR-02:clamp1 | PASS | 0.00 | 1 | +1.00 |
| CLAMP-ON-PATH | HR-02:clamp2 | PASS | 0.00 | 1 | +1.00 |
| CLAMP-ON-PATH | HR-02:clamp3 | PASS | 0.00 | 1 | +1.00 |
| CLAMP-ON-PATH | HR-02:clamp4 | PASS | 0.00 | 1 | +1.00 |
| CLAMP-ON-PATH | HR-02:clamp5 | PASS | 0.00 | 1 | +1.00 |
| CLAMP-ON-PATH | HR-02:clamp6 | PASS | 0.00 | 1 | +1.00 |
| CLAMP-SPACING | HR-01:gap1 | PASS | 100.00 | 200 | +100.00 |
| CLAMP-SPACING | HR-01:gap2 | PASS | 150.00 | 200 | +50.00 |
| CLAMP-SPACING | HR-01:gap3 | PASS | 150.00 | 200 | +50.00 |
| CLAMP-SPACING | HR-01:gap4 | PASS | 150.00 | 200 | +50.00 |
| CLAMP-SPACING | HR-01:gap5 | PASS | 150.00 | 200 | +50.00 |
| CLAMP-SPACING | HR-01:gap6 | PASS | 90.00 | 200 | +110.00 |
| CLAMP-SPACING | HR-01:gap7 | PASS | 60.00 | 200 | +140.00 |
| CLAMP-SPACING | HR-02:gap1 | PASS | 100.00 | 200 | +100.00 |
| CLAMP-SPACING | HR-02:gap2 | PASS | 150.00 | 200 | +50.00 |
| CLAMP-SPACING | HR-02:gap3 | PASS | 150.00 | 200 | +50.00 |
| CLAMP-SPACING | HR-02:gap4 | PASS | 150.00 | 200 | +50.00 |
| CLAMP-SPACING | HR-02:gap5 | PASS | 130.00 | 200 | +70.00 |
| CLAMP-SPACING | HR-02:gap6 | PASS | 110.00 | 200 | +90.00 |
| CLAMP-SPACING | HR-02:gap7 | PASS | 60.00 | 200 | +140.00 |
| CONNECTOR-ACCESS | CN-01/BL-01 | PASS | 80.00 | 60 | +20.00 |
| CONNECTOR-ACCESS | CN-01/BL-02 | PASS | 380.00 | 60 | +320.00 |
| CONNECTOR-ACCESS | CN-01/BM-01 | PASS | 80.00 | 60 | +20.00 |
| CONNECTOR-ACCESS | CN-02/BL-01 | PASS | 80.00 | 60 | +20.00 |
| CONNECTOR-ACCESS | CN-02/BL-02 | PASS | 380.00 | 60 | +320.00 |
| CONNECTOR-ACCESS | CN-02/BM-01 | PASS | 120.42 | 60 | +60.42 |
| FASTENER-LOCKING | F-01 | PASS | 2.00 | 2 | +0.00 |
| FASTENER-LOCKING | F-02 | PASS | 2.00 | 2 | +0.00 |
| FASTENER-LOCKING | F-03 | PASS | 2.00 | 2 | +0.00 |
| FASTENER-LOCKING | F-04 | PASS | 2.00 | 2 | +0.00 |
| FASTENER-LOCKING | F-05 | PASS | 2.00 | 2 | +0.00 |
| FASTENER-LOCKING | F-06 | PASS | 2.00 | 2 | +0.00 |
| FASTENER-LOCKING | F-07 | PASS | 2.00 | 2 | +0.00 |
| FASTENER-LOCKING | F-08 | PASS | 2.00 | 2 | +0.00 |
| FITTING-EDGE-DISTANCE | F-01/FT-01 | PASS | 30.00 | 16 | +14.00 |
| FITTING-EDGE-DISTANCE | F-02/FT-01 | PASS | 30.00 | 16 | +14.00 |
| FITTING-EDGE-DISTANCE | F-03/FT-02 | PASS | 30.00 | 16 | +14.00 |
| FITTING-EDGE-DISTANCE | F-04/FT-02 | PASS | 30.00 | 16 | +14.00 |
| FITTING-EDGE-DISTANCE | F-05/FT-03 | PASS | 30.00 | 16 | +14.00 |
| FITTING-EDGE-DISTANCE | F-06/FT-03 | PASS | 30.00 | 16 | +14.00 |
| FITTING-EDGE-DISTANCE | F-07/FT-04 | PASS | 30.00 | 16 | +14.00 |
| FITTING-EDGE-DISTANCE | F-08/FT-04 | PASS | 30.00 | 16 | +14.00 |
| HARNESS-CLEARANCE | HR-01:seg1/HZ-01 | PASS | 680.00 | 50 | +630.00 |
| HARNESS-CLEARANCE | HR-01:seg1/MP-01 | PASS | 150.00 | 50 | +100.00 |
| HARNESS-CLEARANCE | HR-01:seg2/HZ-01 | PASS | 266.83 | 50 | +216.83 |
| HARNESS-CLEARANCE | HR-01:seg2/MP-01 | PASS | 60.00 | 50 | +10.00 |
| HARNESS-CLEARANCE | HR-01:seg3/HZ-01 | PASS | 266.83 | 50 | +216.83 |
| HARNESS-CLEARANCE | HR-01:seg3/MP-01 | PASS | 208.81 | 50 | +158.81 |
| HARNESS-CLEARANCE | HR-01:seg4/HZ-01 | PASS | 280.18 | 50 | +230.18 |
| HARNESS-CLEARANCE | HR-01:seg4/MP-01 | PASS | 256.12 | 50 | +206.12 |
| HARNESS-CLEARANCE | HR-02:seg1/HZ-01 | PASS | 150.00 | 50 | +100.00 |
| HARNESS-CLEARANCE | HR-02:seg1/MP-01 | PASS | 680.00 | 50 | +630.00 |
| HARNESS-CLEARANCE | HR-02:seg2/HZ-01 | PASS | 60.00 | 50 | +10.00 |
| HARNESS-CLEARANCE | HR-02:seg2/MP-01 | PASS | 296.14 | 50 | +246.14 |
| HARNESS-CLEARANCE | HR-02:seg3/HZ-01 | PASS | 180.28 | 50 | +130.28 |
| HARNESS-CLEARANCE | HR-02:seg3/MP-01 | PASS | 296.14 | 50 | +246.14 |
| HARNESS-CLEARANCE | HR-02:seg4/HZ-01 | PASS | 194.16 | 50 | +144.16 |
| HARNESS-CLEARANCE | HR-02:seg4/MP-01 | PASS | 331.21 | 50 | +281.21 |
| HARNESS-ORTHOGONAL | HR-01:seg1 | PASS | 1.00 | 1 | +0.00 |
| HARNESS-ORTHOGONAL | HR-01:seg2 | PASS | 1.00 | 1 | +0.00 |
| HARNESS-ORTHOGONAL | HR-01:seg3 | PASS | 1.00 | 1 | +0.00 |
| HARNESS-ORTHOGONAL | HR-01:seg4 | PASS | 1.00 | 1 | +0.00 |
| HARNESS-ORTHOGONAL | HR-02:seg1 | PASS | 1.00 | 1 | +0.00 |
| HARNESS-ORTHOGONAL | HR-02:seg2 | PASS | 1.00 | 1 | +0.00 |
| HARNESS-ORTHOGONAL | HR-02:seg3 | PASS | 1.00 | 1 | +0.00 |
| HARNESS-ORTHOGONAL | HR-02:seg4 | PASS | 1.00 | 1 | +0.00 |
| HOLE-PITCH | FT-01:F-01-F-02 | PASS | 84.85 | 24 | +60.85 |
| HOLE-PITCH | FT-02:F-03-F-04 | PASS | 84.85 | 24 | +60.85 |
| HOLE-PITCH | FT-03:F-05-F-06 | PASS | 84.85 | 24 | +60.85 |
| HOLE-PITCH | FT-04:F-07-F-08 | PASS | 84.85 | 24 | +60.85 |
| ICD-CONSISTENCY | Payload mass | PASS | 1.00 | 1 | +0.00 |
| ICD-CONSISTENCY | Payload power voltage | PASS | 1.00 | 1 | +0.00 |
| ICD-CONSISTENCY | Platform attachment spacing | PASS | 1.00 | 1 | +0.00 |
| INSPECTION-ACCESS | IZ-01 | PASS | 170.00 | 0 | +170.00 |
| INSPECTION-ACCESS | IZ-02 | PASS | 170.00 | 0 | +170.00 |
| INSPECTION-ACCESS | IZ-03 | PASS | 170.00 | 0 | +170.00 |
| INSPECTION-ACCESS | IZ-04 | PASS | 170.00 | 0 | +170.00 |
| REMOVAL-CORRIDOR | SM-01 | PASS | 398.25 | 0 | +398.25 |
| REMOVAL-CORRIDOR | SM-02 | PASS | 398.25 | 0 | +398.25 |
| REMOVAL-CORRIDOR | SM-03 | PASS | 420.00 | 0 | +420.00 |
| REMOVAL-CORRIDOR | SM-04 | PASS | 190.00 | 0 | +190.00 |
| REMOVAL-CORRIDOR | SM-05 | PASS | 80.00 | 0 | +80.00 |

## Declared rules

| Rule | Value |
| --- | --- |
| bend_radius_factor | 5 |
| clamp_spacing_max | 200 |
| connector_access_radius | 60 |
| edge_distance_factor | 2 |
| harness_clearance | 50 |
| hole_pitch_factor | 3 |
| inspection_access_radius | 80 |
| minimum_clearance_mm | 25 |

The layout is a two-view 2D envelope model: rectangles, circles and orthogonal harness paths. Three-dimensional interference checking and the strength analysis are separate work, tracked by their own tickets.

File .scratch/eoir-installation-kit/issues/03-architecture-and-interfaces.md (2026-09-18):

# 03: Architecture and interfaces

**What to build:** the architecture model completed and readable — functions with their requirements, components realising the functions, interfaces between kit and boundary (platform structure, payload, bus, mission system, maintainer, environment) — plus a diagram generated from the YAML.

**Blocked by:** 01.

**Status:** resolved

- [x] Every function realised by at least one component, every component realising at least one function
- [x] Every requirement allocated to at least one component; no component without a requirement
- [x] Interface list with both endpoints declared, including the payload interface control data
- [x] A diagram (Mermaid or SVG) generated from the model by a script, not drawn by hand
- [x] `python -m tools.traceability check` green; matrix regenerated

## Answer

Closed on 2026-09-18.

**Interface control data became files.** `model/interfaces/icd_payload.yaml` and
`model/interfaces/icd_platform.yaml` hold the declared interface values (mass and inertia,
envelope, mounting pattern, power, buses, field of view, attachment provisions, structural
environment, certification basis). The assumptions that rest on those values now carry a
`data_file` pointer, and a new rule, `ASM-FILE`, fails the build when the pointer does not
resolve. Seven assumptions point at the two files; one rule test covers the missing-file
case and one covers the accepted case.

**The architecture document is generated.** `tools/diagram.py` renders
`docs/architecture.md` from the model: a Mermaid diagram of the components and the external
boundary with one edge per interface, plus the function, component, interface and external
boundary tables. CI runs `python -m tools.diagram --check`, so the committed document cannot
differ from the model. Mermaid node identifiers cannot contain a hyphen, so the identifiers
are the element ids with hyphens removed and the labels carry the real id.

**Allocation state after the ticket**

| Element | State |
| --- | --- |
| 9 functions | each one realises at least one requirement and is realised by at least one component |
| 12 components | each one owns 2 to 11 requirements, each one realises at least one function |
| 9 interfaces | both endpoints declared, source and target never the same, all endpoints resolve to a component or a declared external |
| 6 externals | platform structure, payload, platform bus, mission system, maintainer, environment |

Model state: 38 requirements, 28 verification cases, 12 components, 12 assumptions, 10 rules,
34 tests. Validator green with 0 errors and 0 warnings; both generated documents current.

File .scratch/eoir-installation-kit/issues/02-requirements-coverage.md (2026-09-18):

# 02: Requirements coverage

**What to build:** the requirement set completed by class — structure and loads, mass and balance, electrical and data interfaces, power, environment and qualification, electromagnetic compatibility, maintainability and access, certification and documentation — with every requirement carrying a verifiable acceptance criterion and a source.

**Blocked by:** 01.

**Status:** resolved

- [x] Every class of the installation covered by at least one requirement
- [x] Every requirement readable as a single verifiable statement (ISO/IEC IEEE 29148 criteria: unambiguous, verifiable, no design imposed)
- [x] Every requirement with a source: a standard clause (`STD`) or a declared assumption (`ASM`)
- [x] Every new assumption written in `model/assumptions.yaml` with rationale and status
- [x] No requirement without an acceptance criterion that the verification case can test
- [x] `python -m tools.traceability check` green; matrix regenerated

## Answer

Closed on 2026-09-18. Fifteen requirements added (`SYS024`–`SYS038`) after a gap review
against 14 CFR Part 27 Subpart D and the DO-160G section list:

| Area | Added |
| --- | --- |
| Structural design rules | `SYS024` fitting factor 1.15 (27.625), `SYS025` material design values (27.613), `SYS026` fastener locking (27.607), `SYS027` protection of structure (27.609), `SYS028` inspection provisions (27.611), `SYS029` critical parts (27.602) |
| Harness, connectors and power distribution | `SYS030` routing and protection, `SYS031` connector retention and access, `SYS032` circuit protection reachable and labelled |
| Environmental breadth | `SYS033` fluids (§11), `SYS034` sand, dust and fungus (§12, §13), `SYS035` lightning and static electricity protection (27.610) |
| Certification and configuration | `SYS036` configuration control, `SYS037` loading information and flight manual effect (27.1589, 27.1583), `SYS038` part identification |

Twelve verification cases (`VER017`–`VER028`) and their evidence records were added, all
`FUTURE` with the ticket that will produce the evidence. One assumption was added
(`A-012`, harness installation rules) and one component (`CMP-12`, harness routing and
protection provisions), which realises four functions. One interface was added (`IF-09`).

Clause numbers were verified against the public text of 14 CFR Part 27 (Subpart D and
Subpart G) before being cited; no clause is quoted from memory.

Model state after the ticket: 38 requirements, 28 verification cases, 12 components, 9
functions, 9 interfaces, 12 declared assumptions, validator green with 0 errors and 0
warnings.

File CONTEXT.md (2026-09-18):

# Glossary

The vocabulary of this repository. One term, one meaning. If a document in this repository
uses a word that is not here and is not standard domain language, that is a gap.

- **Installation kit (the kit)**: the product under study. The structural attachment, the
  electrical and avionic interfaces, the bonding, the environmental provisions and the
  documentation that let the platform carry the payload. The kit is the subject of every
  requirement in this repository.
- **Payload**: the stabilised EO/IR unit that the kit carries. It is an input to the study,
  described by declared interface data, never by a supplier data sheet.
- **Platform**: the CS-27 class light helicopter or tactical UAV that carries the kit. Its
  structure, bus and mission system are the external boundary of the study.
- **Requirement (`SYS`)**: a statement the installation must satisfy, written with a
  *source* (`STD` citation or `ASM` assumption) and an acceptance criterion that can be
  verified. Requirements live in the Doorstop document under `model/requirements`.
- **Verification case (`VER`)**: the statement of *how* a requirement is shown to be
  satisfied, with a method. A verification case links to the requirement it closes and has
  exactly one evidence record.
- **Method**: how a verification case is executed — `analysis`, `simulation`, `test`,
  `inspection`, `demonstration` or `review`.
- **Evidence**: the state of a verification case: the method, the status, the artifact and
  the plan. Evidence lives in `model/evidence.yaml`, one record per verification case.
- **Artifact**: the file in this repository that contains the result of a verification.
  A `PASS` or `WARN` status without an artifact that exists is a broken claim, and the
  validator rejects it.
- **Status**: `PASS`, `WARN`, `FAIL`, `LIMITATION`, `BLOCKED` or `FUTURE`. `FUTURE` means
  the verification has not been executed and carries the ticket that will execute it.
  A `WARN` is never promoted to a `PASS`.
- **Declared assumption (`ASM`)**: an input the study needs and cannot derive — payload
  mass and envelope, platform data, environmental categories, maintainability targets.
  Assumptions have a status (`OPEN`, `CLOSED`, `REJECTED`) and are the first thing to
  challenge. Evidence produced against an `OPEN` assumption is reported as a warning. An
  assumption that rests on interface data declares it in `data_file`, and the `ASM-FILE`
  rule rejects a pointer to a file that does not exist.
- **Layout**: the dimensional definition of the kit, in `model/layout.yaml` at revision A:
a two-view 2D envelope model (side and bottom view) with rectangles, circles and orthogonal
harness paths. It is the single source of truth for every dimension, and the geometric checks
in `tools/layout.py` run against it.
- **Layout check**: one of the geometric or data checks on the layout, each with a stable
identifier (`REMOVAL-CORRIDOR`, `CONNECTOR-ACCESS`, `FITTING-EDGE-DISTANCE`, `HOLE-PITCH`,
`FASTENER-LOCKING`, `INSPECTION-ACCESS`, `HARNESS-ORTHOGONAL`, `BEND-RADIUS`,
`CLAMP-ON-PATH`, `CLAMP-SPACING`, `HARNESS-CLEARANCE`, `ICD-CONSISTENCY`). A failing check
stops the tool and names the violated constraint.
- **Swept sector**: the volume the rotating head of the payload sweeps around its gimbal
  axis, bounded by the declared elevation range. In the side view it is a circular sector;
  `tools/clearance.py` samples it with one ray per declared step and checks every ray against
  the structure and the platform skin. The sector exists only with the payload installed.
- **Interface control data (ICD)**: the declared values of the payload and the platform
  interfaces — mass and inertia, envelope, mounting pattern, power, buses, field of view,
  attachment provisions, structural environment. They live in `model/interfaces/` and are
  inputs of the study, not supplier data.
- **Load case**: one inertia condition of the installation, derived by `tools/loads.py` from a
  declared acceleration and a declared load factor — the payload and kit mass accelerated in a
  direction. The cases are not listed in the model: they are computed, so changing the platform
  data changes the analysis.
- **Limit load**: the maximum load expected in service. A condition the platform prescribes as
  a limit load takes the factor of safety of 14 CFR 27.303 to reach the ultimate load.
- **Ultimate load**: the limit load multiplied by the factor of safety. A condition the
  platform prescribes as an ultimate load — the emergency landing inertia factors — takes no
  further factor, which is what 27.303 says.
- **Factor of safety**: 1.5 unless the condition is already prescribed as ultimate. The applied
  factor is checked per case against the factor that case requires, so the bookkeeping is
  visible instead of implied.
- **Load path**: the chain that carries the load from the payload centre of gravity to the
  platform structure — interface plate, frame rails, fittings, fasteners, hard points. Each
  element names the section it is checked at in `model/loads.yaml`.
- **Attachment plane**: the plane of the platform provisions the fittings bolt to, taken at the
  platform skin in the layout. The payload centre of gravity sits below it, so a horizontal
  inertia force produces a couple that the fittings resist in pairs.
- **Excitation band**: the frequency range of a rotor harmonic over the declared rotor speed
  range, widened by the declared separation percentage. **Admissible window**: a frequency range
  clear of every band. SYS015 requires the installation to stay out of the bands, which is a
  statement about the installation, not about the bands.
- **Limitation class**: why the study cannot make a statement — `INPUT` (a declared
  input is missing or unconfirmed), `METHOD` (the method cannot show it), `ARTICLE`
  (it needs a physical article), `AUTHORITY` (it needs the platform, the installer or
  the competent authority), `INDEPENDENCE` (the limitation of the review itself). The
  class is written once, in `model/report.yaml`, and the review refuses a limitation
  without one.
- **Review**: the mechanical check of the package: the model, the evidence files, the
  numbers the documents quote and the tickets still open, read by `tools/report.py`.
  It is reproducible and it is not independent — the study has one author — and the
  report states that instead of letting the word suggest otherwise.
- **Installation zone**: a place the installation occupies, with the environmental exposure
  that comes with it — the external belly bay and the unpressurised fuselage interior in this
  study, plus a zone for what is not installed. The zone is what a DO-160G category encodes, so
  the zone definition belongs to the platform and the category selection is a joint decision.
- **Category**: the severity an equipment is qualified to within a DO-160G section. It is
  written in `model/qualification.yaml` only where a declared input of this study and a public
  statement about the standard fix it; otherwise the entry names the input the category waits
  for. The standard itself is not in this repository.
- **Qualification state of an entry**: `ASSESSED` when the design already answers it by analysis
  or inspection, `PLANNED` when it needs a test on an article, `OPEN` when the selection cannot
  be completed with the declared inputs.
- **Protection preservation**: the argument that the installation keeps the lightning, HIRF and
  bonding characteristics the platform protection plan gives it, recorded with the means the
  installation provides and what cannot be checked because the plan is referenced, not held.
- **Architecture element**: a function (`FCT`), a component (`CMP`) or an interface
  (`IF`). Each one declares the requirements allocated to it; each requirement is owned by
  at least one component.
- **External (`EXT`)**: something outside the study boundary that the kit touches — the
  platform structure, the payload, the bus, the mission system, the maintenance crew, the
  environment.
- **Allocation**: the link from a requirement to the architecture element that realises it.
- **Traceability**: the chain requirement → architecture element → verification case →
  evidence record. The chain is enforced by `tools/rules.py`.
- **Traceability matrix**: the generated table in `docs/traceability.md` that shows the
  chain and the state of every link. Generated from the model; never edited by hand.
- **Change classification**: the assessment, under EASA Part 21 Subpart D, of whether the
  installation is a minor or major change to the type design. It has to be recorded before
  release, not assumed. The study records it in `model/compliance.yaml` with one criterion per
  appreciable effect and keeps the status `OPEN` until the platform procedure confirms it.
- **Compliance document**: a document in the register that shows compliance with the
  requirements it covers. Every requirement is covered by exactly one document; the coverage
  is enforced by the `COMPLIANCE-COVERAGE` rule.
- **Document register**: the list of compliance documents in `model/compliance.yaml`: identity,
  title, type, state, the requirements each one covers and the ticket that will produce it.
  States: `PLANNED`, `DRAFT`, `OUTLINE`, `GENERATED`, `ISSUED`.
- **Compliance data**: the set of documents that demonstrate satisfaction of the
  requirements — compliance matrix, drawings list, analysis reports, test plans and
  reports.

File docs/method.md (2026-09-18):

# Method

How the model is built, what holds it together, and what has been left out on purpose.

## The four parts

| Part | File | Owns |
| --- | --- | --- |
| Requirements | `model/requirements/SYS*.yml` (Doorstop) | what the installation must satisfy |
| Verification cases | `model/verification/VER*.yml` (Doorstop) | how each requirement is shown to be satisfied |
| Architecture | `model/architecture/architecture.yaml` | functions, components, interfaces and who owns what |
| Interface control data | `model/interfaces/icd_payload.yaml`, `model/interfaces/icd_platform.yaml` | the declared payload and platform interface values |
| Evidence | `model/evidence.yaml` | method, status, artifact and plan of every verification case |

Declared assumptions live in `model/assumptions.yaml` and are referenced by the requirements
that depend on them. An assumption that rests on interface data carries a `data_file` pointer,
and the `ASM-FILE` rule fails the build when that file is missing.

## Why Doorstop

Doorstop keeps requirements as versioned YAML items and checks their links. In this
repository it owns the requirement-to-verification link (`VER` items link to `SYS` items)
and the requirement text itself. Two Doorstop checks are disabled in CI and in
`tools/model.py`:

- **external reference check** — the `ref` field carries a *citation* (`STD 14 CFR 27.303`,
  `ASM A-006`), not a file path or a URL. `tools/rules.py` checks the citation syntax and
  resolves every `ASM` against the assumptions register.
- **level check** — the two documents are flat lists, so every item sits at level 1.

Both are visible in the CI command (`doorstop --no-ref-check --no-level-check`), not hidden
in a configuration file. Every other Doorstop check runs.

## Why the validator exists

`docs/architecture.md` and `docs/traceability.md` are both generated: the first by
`tools/diagram.py` (Mermaid diagram and allocation tables), the second by
`tools/traceability.py` (the requirement matrix). CI fails when either file differs from
the model, so the published documents cannot drift.

Doorstop knows nothing about the architecture and nothing about evidence. The chain that
matters for this study is longer than a requirement tree:

```
requirement → architecture element → verification case → evidence record → artifact
```

`tools/rules.py` enforces the whole chain with one rule identifier per failure, so a red
build points at a rule, not at an opinion. The rules are the contract:

- no requirement without a source;
- no requirement without an owning component;
- no architecture element without a requirement, no interface with an unknown endpoint;
- no requirement without a verification case, no verification case without an evidence record;
- no `PASS`/`WARN` without an artifact that exists;
- no `FUTURE` without a plan, no `LIMITATION`/`FAIL`/`BLOCKED` without a note;
- a warning when evidence is produced against an assumption that is still open.

## The layout and its checks

`model/layout.yaml` is the single source of truth for every dimension of the kit: a
two-view 2D envelope model (rectangles, circles and orthogonal harness paths, in
millimetres). `tools/layout.py` runs twelve geometric and data checks on it — removal
corridor, connector access, fitting edge distance, hole pitch, fastener locking, inspection
access, harness orthogonality, bend radius, clamp position and spacing, clearance to hot
zones and moving parts, and agreement with the interface control data — and writes four
files into `evidence/layout/`: the machine-readable `checks.json`, a readable `report.md`, an
SVG figure and a DXF R12 export. CI runs `python -m tools.layout --check`, so the published
evidence cannot differ from the model.

## The field of view and the clearance

`model/layout.yaml` declares the gimbal centre, the head radius and the sampling step of the
swept sector; the elevation range is read from the payload interface data, so those numbers
live in one place. `tools/clearance.py` samples the sector with one ray per step and checks
every ray against the declared structure and the platform skin: no obstruction, no ray
reaching the skin, and a minimum clearance of at least the declared value. The report lists
the clearance direction by direction and flags the directions whose margin is inside twice
the limit, so a tight direction is reported instead of averaged away. A figure of the sector
with the rays is generated into `evidence/clearance/sweep.svg`.

## The electrical budget

`model/power.yaml` declares the kit harness conductors, the protection device and the design
rules; the payload demand and the bus data come from the interface control files.
`tools/power.py` computes the continuous and peak currents, the voltage drop along each
harness, the conductor ampacity, the breaker rating against the peak demand and the resulting
bus load, and writes `evidence/power/`. The items the declared data cannot close — above all
the payload inrush against the breaker rating, which needs the trip curve — are listed in the
evidence as open items instead of being smoothed away.

## The load path

`model/loads.yaml` declares the material allowables, the structural idealisation and the
design rules; the payload mass and centre of gravity, the platform accelerations, the
attachment geometry and the available clearance come from the rest of the model.
`tools/loads.py` derives the load cases from the declared accelerations, runs each one through
the load path — payload, plate, frame rails, fittings, fasteners, platform hard points — and
checks the reaction, the critical section stress, the bearing, the shear and tension
interaction in the fasteners, and the deflection against the clearance margin the field of view
analysis left. It also compares its own solution with an independent closed form and reports
the difference, and it computes the rotor excitation bands the first mode has to stay clear of.

The result is stated as it is: the strength margins are two orders of magnitude wide, so
strength is not what sizes this installation, while the resonance separation cannot be
demonstrated by a single degree of freedom estimate whose uncertainty is wider than the gaps
between the harmonics.

## The qualification plan

`model/qualification.yaml` declares the installation zones, the DO-160G sections that reach
each of them, the category of a section or the input it is still open on, the method and the
test article, the protection means the installation provides and the open items.

`tools/qualification.py` checks that the plan covers every section the requirements cite, that
every entry is complete — a zone, a basis, a category or an explicit open item, a method, an
article where a test is needed, a limitation where the work is pending — that every component
is placed in a zone, that every zone is reached or declared exempt, and that the plan is the
document TP-001 of the compliance register. It also writes the plan itself into
`docs/qualification-plan.md`, so the document and the checks that review it cannot drift apart.

Categories are not invented. The standard is not in this repository, so a category is written
down only where a declared input of the study and a public statement about the standard fix it:
the temperature family for an external bay, the waterproofness category for externally mounted
equipment, the power input category for 28 Vdc equipment, the vibration family for rotary wing.

## The report and the review

`model/report.yaml` declares the narrative of the technical report, the limitations
register with the class of every limitation, the review criteria and the numbers the
repository documents quote. `tools/report.py` renders `docs/report.md` from that
narrative and from the evidence files, so a figure in the report is read from the
artifact it comes from and cannot drift from it.

The same tool runs the review, against the model and the evidence rather than against
the prose: every analysis the report quotes has an evidence file that exists and
reports no failure, every passed case names an artifact that exists, no case carries
the warning status, every case still to come points at a ticket that exists, every
limitation is classified in both directions, and every number the documents quote
matches the model. The study has one author, so the review is mechanical and not
independent, and the report says so rather than implying otherwise.

## The compliance frame

`model/compliance.yaml` holds two things: the change classification (one criterion per
appreciable effect, the approval route and the privileges it relies on) and the document
register, which assigns every requirement to exactly one document — the one that will show
compliance. `tools/compliance.py` renders `docs/compliance-matrix.md` from it, and the
`COMPLIANCE-COVERAGE` rule fails the build when a requirement has no document or two. The
instructions for continued airworthiness are outlined in `docs/ica.md`.

## How to add a requirement

1. `doorstop add SYS` in `model/requirements`, then write `header`, `text` and `ref`
   (`STD <citation>` and/or `ASM <id>`).
2. Allocate it to at least one component in `model/architecture/architecture.yaml`.
3. Add a `VER` item that links to it, and an evidence record for that `VER`.
4. Add it to exactly one document in `model/compliance.yaml`.
5. If it is an installation requirement, add the geometry to `model/layout.yaml` and the
   mass to `model/mass.yaml`.
6. Run `python -m tools.traceability check`, the analysis tools (`layout`, `mass`,
   `clearance`), `python -m tools.traceability report` and `python -m tools.compliance`.

## How to close a verification case

Paths in the evidence record are relative to the repository root for `artifact`
(`evidence/...`) and relative to `.scratch/eoir-installation-kit/` for `plan`
(`issues/04-analysis-mass-and-balance`).

1. Produce the artifact (analysis script and its output, test report, review record).
2. Put the path in the `artifact` field of the evidence record and set the status.
3. If the evidence depends on a declared assumption, say so: if the assumption is still
   `OPEN` the validator emits the `ASM-OPEN` warning, and the warning stays until either the
   assumption is closed or the limitation is accepted in writing.

## What this method gives up

It is not a SysML model and it is not a Capella model: there is no graphical notation, no
simulable functional model, no tool-level metamodel exchange (ReqIF, XMI). The layout is a
2D envelope model, not 3D CAD: interference checking in three dimensions is separate work.
What it gives is a model that a reviewer can read in a diff, that CI can check, and that
does not depend on a licence. The trade-off is recorded in `docs/adr/0001`.

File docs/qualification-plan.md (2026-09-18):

<!-- Generated by tools/qualification.py — do not edit by hand. -->
<!-- Run: python -m tools.qualification -->

# Environmental qualification plan

| | |
| --- | --- |
| Document | TP-001 of the compliance register |
| Standard | RTCA DO-160G / EUROCAE ED-14G |
| Revision | A |
| Installation | EO/IR installation kit on a CS-27 class platform |

## Purpose and scope

This plan states which sections and categories of the standard the installation has to be
qualified to, in which installation zone, by which method and on which article. It covers
the kit and the payload interface: the payload is qualified by its supplier, and this plan
covers what the installation does to it.

Two things are deliberately not done here. First, a category is not invented: the standard
is not part of this repository, so a category is written down only where a declared input of
the study and a public statement about the standard fix it, and every other entry names what
the category depends on. Second, no compliance is claimed: the plan says what will show it,
and the states below are what the study can reach without an article.

## What the plan rests on

| Statement used to select sections and categories | Source |
| --- | --- |
| Equipment is qualified to a specific severity category within each applicable section, and the selection is determined by the installation location, the aircraft category and the certification basis. | published summaries of DO-160 by qualification laboratories |
| Section 4 categories run from A1 for pressurised cockpit locations to D3 for unpressurised external mounting, with temperature ranges from -55 to +85 degrees Celsius and altitudes up to 21 300 metres. | published summaries of DO-160 Section 4 |
| Section 7 operational shock applies to equipment on aircraft and rotorcraft; the crash safety test applies only where equipment coming loose could present a hazard in an emergency landing, such as fuel system and evacuation equipment, and it is not required to function afterwards. | published summaries of DO-160 Section 7 |
| Section 8 categories are S (standard, fixed wing), R, U and U2 (robust, including rotary wing) and H and Z (high level short duration); R and U are the rotary wing robust categories, tested sine-on-random, and the curve comes from the table of categorisation by aircraft type and equipment location. | published summaries of DO-160 Section 8 |
| Section 10 has four categories: W for dripping condensation, R for dripping water, S for spray and T for externally mounted equipment subject to direct rainfall and washing. | published summaries of DO-160 Section 10 |
| Section 16 category Z is 28 Vdc equipment that may be used on all other types of electrical system, and it is acceptable for use in lieu of category A or category B. Category B is 14 V or 28 Vdc equipment where a battery of significant capacity floats on the bus at all times; category A is 28 Vdc equipment whose dc comes from transformer-rectifier units fed from an ac system. | published reference material for DO-160 Section 16 |
| Section 20 categories run from B for routine commercial aviation to R and W for high intensity radiated field environments. | published summaries of DO-160 Section 20 |
| Section 21 limits depend on the sensitivity of the aircraft receivers to interference and on the proximity of the wiring to those receivers. | published summaries of DO-160 Section 21 |
| Section 23 applies to externally mounted equipment with external apertures, such as antennas and sensors. | published summaries of DO-160 Section 23 |
| Section 26 applies to all equipment, and cabin equipment carries the most stringent flammability requirements. | published summaries of DO-160 Section 26 |

The category of a section encodes the installation zone, and the zone definition belongs to
the platform. The closing authority is therefore joint:

> The design organisation with the platform installer and the competent authority. The category of a section is a joint decision with the platform, because the category encodes the installation zone the platform owns.

## Installation zones

| Zone | Where | Exposure | Source of the definition | Components |
| --- | --- | --- | --- | --- |
| Z-01 | External belly bay | Unpressurised, outside the platform skin: rain, spray, ground washing, sand and dust, salt, de-icing and cleaning fluids, ground handling, static charge and direct lightning attachment risk. | model/layout.yaml, side view: the payload envelope, the frame and the fittings below the skin line | CMP-01, CMP-02, CMP-03, CMP-04, CMP-05, CMP-07, CMP-08, CMP-09, CMP-11, CMP-12 |
| Z-02 | Unpressurised fuselage interior, protection assembly and mission system panel | Unpressurised interior: condensation, compartment temperature, airframe vibration, and the fluids and dust that reach an equipment bay. | model/interfaces/icd_platform.yaml declares the circuit breakers in the distribution panel and the ARINC 429 interface on the mission system panel | CMP-04, CMP-05, CMP-06, CMP-12 |
| Z-03 | Not installed | none — documentation, marking and ground equipment carried with the kit | model/architecture/architecture.yaml, CMP-10 (documentation and marking set) | CMP-10 |

## Applicability matrix

24 entries: 3 assessed now, 15 planned on an article, 6 open on a platform input. 6 zone selections carry a category (31 are open on a named input).

| Section | Title | Requirement | Z-01 | Z-02 | Z-03 | Method | Status |
| --- | --- | --- | --- | --- | --- | --- | --- |
| 4 | Temperature and Altitude | SYS014 | D | open | — | TEST | PLANNED |
| 5 | Temperature Variation | SYS014 | open | open | — | TEST | OPEN |
| 6 | Humidity | SYS014 | open | open | — | TEST | OPEN |
| 7.2 | Operational Shock | SYS014 | open | open | — | TEST | PLANNED |
| 7.3 | Crash Safety | SYS004 | not-applicable | — | — | ANALYSIS | ASSESSED |
| 8 | Vibration | SYS014 | R or U | R or U | — | TEST | PLANNED |
| 9 | Explosive Atmosphere | SYS014 | not-applicable | not-applicable | — | REVIEW | ASSESSED |
| 10 | Waterproofness | SYS014 | T | not-applicable | — | TEST | PLANNED |
| 11 | Fluids Susceptibility | SYS033 | open | open | — | TEST | PLANNED |
| 12 | Sand and Dust | SYS034 | open | not-applicable | — | TEST | PLANNED |
| 13 | Fungus | SYS034 | not-applicable | not-applicable | — | INSPECTION | ASSESSED |
| 14 | Salt Fog | SYS014 | open | not-applicable | — | TEST | PLANNED |
| 15 | Magnetic Effect | SYS014 | open | open | — | ANALYSIS | OPEN |
| 16 | Power Input | SYS014 | Z | Z | — | TEST | PLANNED |
| 17 | Voltage Spike | SYS014 | open | open | — | TEST | PLANNED |
| 18 | Audio Frequency Conducted Susceptibility | SYS014 | open | open | — | TEST | PLANNED |
| 19 | Induced Signal Susceptibility | SYS014 | open | open | — | TEST | PLANNED |
| 20 | Radio Frequency Susceptibility | SYS014 | open | open | — | TEST | PLANNED |
| 21 | Emission of Radio Frequency Energy | SYS016 | open | open | — | TEST | OPEN |
| 22 | Lightning Induced Transient Susceptibility | SYS035 | open | open | — | TEST | PLANNED |
| 23 | Lightning Direct Effects | SYS035 | open | not-applicable | — | TEST | OPEN |
| 24 | Icing | SYS014 | open | not-applicable | — | TEST | OPEN |
| 25 | Electrostatic Discharge | SYS035 | open | open | — | TEST | PLANNED |
| 26 | Fire and Flammability | SYS014 | open | open | — | TEST | PLANNED |

`not-applicable` means the section does not reach the zone; `open` means the category
cannot be fixed with the declared inputs; `—` means the zone is not in the entry.

## Why each selection is what it is

### Section 4 — Temperature and Altitude

The external bay is unpressurised external mounting, which is the D family. The declared payload environment is -40 to +55 degrees operating and -55 to +85 storage, against the -55 to +85 the section spans, so the declared envelope sits inside the section with no margin at the storage limits.

- **Z-01**: category D — the severity number (D1, D2 or D3) and the altitude profile, which follow from the platform design altitude still open.
- **Z-02**: category open on the family and the severity number for an unpressurised compartment: the published summary places A1 at a pressurised cockpit and D3 at unpressurised external mounting, and the intermediate families are not documented outside the standard.

Method: TEST on payload and kit first article, installed on the platform. State: PLANNED.

Limitation: The ground survival and operating temperatures of the kit itself are not declared: only the payload envelope is, and the kit carries no powered item except the protection assembly.

Closing action: The platform declares its design altitude and compartment map; the categories follow.

### Section 5 — Temperature Variation

The section ramps the equipment between its temperature extremes; the ramp rate belongs to the platform thermal environment and is not declared.

- **Z-01**: category open on the ramp rate of the zone.
- **Z-02**: category open on the ramp rate of the compartment.

Method: TEST on payload and kit first article. State: OPEN.

Limitation: No thermal model of the installation exists in this study.

### Section 6 — Humidity

Both zones are unpressurised and exposed to condensation; the published severities are standard and severe, and the choice follows from how wet the zone is in service.

- **Z-01**: category open on whether the standard or the severe severity applies.
- **Z-02**: category open on whether the standard or the severe severity applies.

Method: TEST on kit first article, with the interface plate and the harnesses installed. State: OPEN.

Limitation: The sealing and drainage provisions are designed but not validated against a severity level.

### Section 7.2 — Operational Shock

Operational shock applies to equipment installed on rotorcraft, and the published statement is that rotorcraft installations face the most demanding profiles.

- **Z-01**: category open on the level.
- **Z-02**: category open on the level.

Method: TEST on kit first article with a mass-representative payload. State: PLANNED.

Limitation: A representative payload mass is used in place of the real payload.

### Section 7.3 — Crash Safety

The crash safety test applies where equipment coming loose could present a hazard in an emergency landing, such as fuel system and evacuation equipment. A belly installation outside the cabin, the fuel bays and the evacuation routes is not such a place, so the section is not applied and the crash inertia loads are instead carried by the structural analysis.

- **Z-01**: the section does not apply.

Method: ANALYSIS. State: ASSESSED.

Limitation: The structural analysis is quasi-static and the crash case rests on declared platform factors rather than on a clause of 27.561 for a belly installation.

### Section 8 — Vibration

For a rotary wing installation the robust categories R and U apply, tested sine-on-random; U repeats the exposure three times where R runs once. The existing structural resonance estimate is a separate limitation and does not qualify the equipment.

- **Z-01**: category R or U — the curve, which comes from the categorisation by aircraft type and equipment location, and the choice between R and U still open.
- **Z-02**: category R or U — the curve, as above still open.

Method: TEST on kit first article with the payload, before and after the endurance exposure. State: PLANNED.

Limitation: The resonance separation is not demonstrated (VER011): the single degree of freedom estimate lands inside the rotor bands, and neither the test above nor the analysis can close that until the modes are measured.

### Section 9 — Explosive Atmosphere

The section applies to zones where fuel vapour may accumulate. The belly bay and the distribution panel are not fuel vapour zones, and the platform confirms it because the fuel system layout is outside this study.

- **Z-01**: the section does not apply.
- **Z-02**: the section does not apply.

Method: REVIEW. State: ASSESSED.

Limitation: The non-applicability rests on the platform confirming that no fuel vent or tank zone reaches the installation.

### Section 10 — Waterproofness

Category T covers externally mounted equipment subject to direct rainfall and washing, which is the belly bay. The interior bay is not exposed to water.

- **Z-01**: category T.
- **Z-02**: the section does not apply.

Method: TEST on kit first article, installed, including the connectors and the harness entries. State: PLANNED.

Limitation: The washing procedure and frequency come from the operator and are not declared.

### Section 11 — Fluids Susceptibility

The published fluid families are hydraulic fluid, fuels, lubricating oils, de-icing and anti-icing compounds, cleaning agents and extinguishing agents. The belly bay sees what drips from above and what is sprayed or washed; the interior bay sees what leaks into the compartment.

- **Z-01**: category open on which fluid families reach the installation.
- **Z-02**: category open on which fluid families reach the compartment.

Method: TEST on kit first article with a representative payload interface. State: PLANNED.

Limitation: The fluid list of the platform is not declared, so the test fluids cannot be fixed: the plan names the families and the platform has to select them.

### Section 12 — Sand and Dust

The section applies to equipment in unpressurised zones or aircraft operated in desert or high particulate environments, which is the belly bay.

- **Z-01**: category open on the severity, which follows from whether the platform operates from unimproved surfaces.
- **Z-02**: the section does not apply.

Method: TEST on kit first article, with the payload envelope closed and with it removed. State: PLANNED.

Limitation: The declared operating environment of the platform does not fix whether unimproved surfaces are used.
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

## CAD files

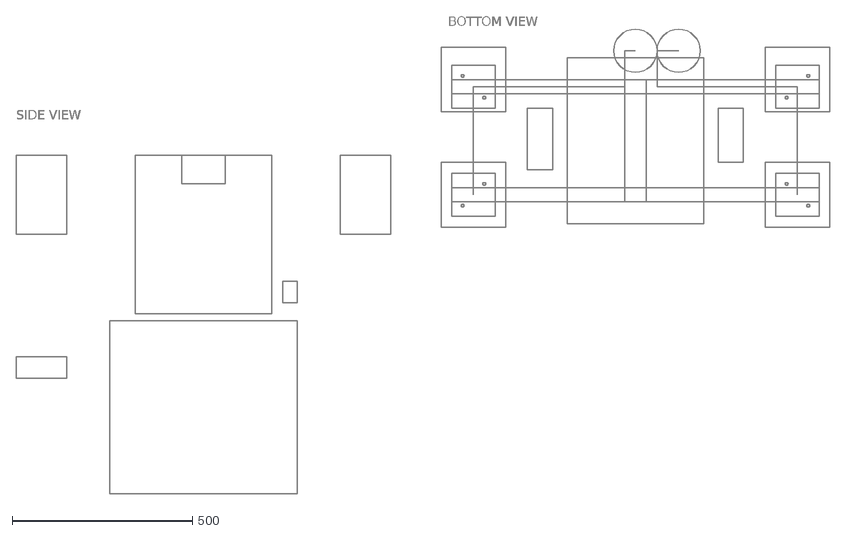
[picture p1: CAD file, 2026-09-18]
evidence/layout/layout.dxf
SIDE VIEW
BOTTOM VIEW

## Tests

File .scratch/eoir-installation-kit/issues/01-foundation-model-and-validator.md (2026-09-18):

# 01: Foundation of the model and the validator

**What to build:** the repository, the four parts of the model (requirements, verification cases, architecture, evidence register), the assumption register, the validation rules, the generated traceability matrix, the test suite, the CI pipeline and the README — enough that a reader can open the repository and check the study in two commands.

**Blocked by:** None (can start immediately).

**Status:** resolved

- [x] Doorstop documents `model/requirements` (SYS) and `model/verification` (VER, linked to SYS)
- [x] Architecture model with functions, components, interfaces and externals
- [x] Evidence register with one record per verification case; every record `FUTURE` with a plan
- [x] Assumption register with statuses and rationales
- [x] One validation rule per failure mode, each with a stable identifier
- [x] `python -m tools.traceability check` green on the repository model
- [x] `docs/traceability.md` generated by the tool and committed
- [x] Unit test per rule, integration tests on the repository model, CLI tests
- [x] CI runs Doorstop, the validator, the freshness check and the tests
- [x] README with what the repository is, what it is not, and the status of the evidence

## Answer

Built on 2026-09-18. 23 requirements (SYS001–SYS023), 16 verification cases (VER001–VER016),
11 components, 9 functions, 8 interfaces, 11 declared assumptions. The validator reports
0 errors and 0 warnings; the suite is green; `docs/traceability.md` is generated by
`python -m tools.traceability report`. Every verification case is `FUTURE` and points at the
ticket that will produce its evidence.

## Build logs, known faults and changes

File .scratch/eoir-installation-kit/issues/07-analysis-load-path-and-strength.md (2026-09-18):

# 07: Load path and strength

**What to build:** the load cases, the load path through the attachment fittings and the frame, the factor-of-safety check and the resonance separation assessment — with the analysis script and its output committed as evidence.

**Blocked by:** 02, 08.

**Status:** resolved

- [x] Load case set derived from the payload mass and envelope, the manoeuvre and gust envelope and the emergency landing inertia conditions
- [x] Internal load path stated and the critical section identified per fitting
- [x] Factor of safety 1.5 applied to limit loads, results against allowable with the margin stated (SYS002, SYS003)
- [x] Resonance separation from the declared rotor excitation frequencies (SYS015)
- [x] Where a closed-form hand calculation and the script disagree, the difference is investigated, not averaged
- [x] Output committed under `evidence/` and referenced by VER001, VER002 and VER011
- [x] Matrix regenerated

## Answer

Closed on 2026-09-18. `model/loads.yaml` declares the material allowables, the structural
idealisation and the design rules; `tools/loads.py` derives the seven load cases from the
declared accelerations, runs each one through the load path and writes `evidence/loads/`
(`checks.json`, `report.md`, 44 checks, all passing).

**The geometry was wrong before the loads could be run.** The four attachment points did not
form the rectangle the platform interface control file declares: the two aft fittings carried
bolt patterns at 140 mm and 170 mm where the forward pair sat at 150 mm, giving a lateral
spacing of 320 mm against the declared 300 mm, and one of the two aft patterns had its two
holes collinear instead of mirrored. The load path shares the reaction equally between four
fittings, so the defect was fixed in `model/layout.yaml` (both aft fittings moved to the
mirror position) and a check was added that would have caught it: `ATTACHMENT-SPACING` measures
the bolt-pattern centres against the platform provisions, and `ATTACHMENT-PATTERN` fails when
the four centres are not a rectangle. 93 layout checks now.

**The load cases, and which one governs.** Five of the seven are listed in the platform data;
the two manoeuvre cases are limit loads and take the factor of safety, the emergency landing
conditions are prescribed as ultimate and take none.

| Case | Basis | Prescribed | Ultimate | Force | Governing fitting |
| --- | --- | --- | --- | --- | --- |
| LC-MAN-UP | limit | 3.5 g | 5.25 g | 3052 N | 763 N |
| LC-MAN-DOWN | limit | −1.0 g | −1.5 g | 872 N | 218 N |
| LC-EML-UP | ultimate | 3.0 g | 3.0 g | 1744 N | 436 N |
| LC-EML-DOWN | ultimate | 3.0 g | 3.0 g | 1744 N | 436 N |
| LC-EML-FWD | ultimate | 4.0 g | 4.0 g | 2325 N | 600 N |
| LC-EML-AFT | ultimate | 4.0 g | 4.0 g | 2325 N | 600 N |
| LC-EML-LAT | ultimate | 2.0 g | 2.0 g | 1163 N | 366 N |

**The manoeuvre case governs, not the emergency landing**: the factor of safety lifts 3.5 g of
limit manoeuvre to 5.25 g of ultimate load, more than the 3.0 g the platform declares for the
crash case. Everything downstream is sized by that case.

**A vertical force makes no couple, a horizontal one does.** The payload centre of gravity sits
115 mm below the attachment plane — derived from the payload interface data and the layout
envelope, not typed in. A vertical inertia force acts along the centre of the attachment
pattern, so it divides equally between the four fittings. A horizontal force acts *below* the
plane: it adds a couple, and the fittings resist it in pairs, 148.6 N of tension or compression
when the payload pushes forward at 4 g.

**The strength checks are not what sizes this installation.**

| Check | Worst value | Limit | Margin |
| --- | --- | --- | --- |
| `LOADS-HARD-POINT` | 763 N | 25 000 N per point | +24 237 N |
| `LOADS-FITTING-NET-SECTION` | 15.26 MPa | 310 MPa | +295 MPa |
| `LOADS-BEARING` | 4.77 MPa | 390 MPa | +385 MPa |
| `LOADS-BOLT` (shear and tension interaction) | 0.019 | 1.0 | +0.98 |
| `LOADS-LIMIT-STRESS` at limit load | 10.17 MPa | 260 MPa (Fty) | +250 MPa |

At the critical section of the fitting the analysis combines three effects — bending from the
direct share over the declared lever, axial stress from the couple, and the in-plane shear —
by the combination rule declared in the model, because comparing only the largest one with the
allowable would flatter the result.

**The hand calculation and the script agree on the components and disagree on the total, and
the difference is the interesting part.** On LC-EML-FWD the closed form gives 581.3 N of direct
share and 148.6 N of couple share; the general solution gives the same two numbers to within
0.00 %, which is what `LOADS-HAND-CHECK` verifies. But the closed form adds them — 730 N —
while the general solution resolves them as a vector — 600 N, **+21.6 %**. The two shares act
on different axes, so adding them is not a conservative simplification but a different
quantity. It errs on the safe side for a hand calculation, and it would be the wrong number to
publish: the checks use the resultant.

**Deflection fits inside the clearance the field of view analysis left.** Under LC-MAN-UP at
limit load the payload moves 2.18 mm relative to the platform, with the load path stiffness of
933 N/mm and the softest support idealisation, which is the one that gives the largest
movement. The tightest direction of the swept sector has 30 mm against a requirement of 25 mm,
so 5 mm were available: the movement uses 44 % of the margin. This is the first time the
structural analysis and the geometric analysis have been checked against each other, which is
what SYS009 asks for and what a single discipline would have missed.

**The resonance separation is not demonstrated, and the analysis says why.** The excitation
bands are computed from the declared rotor speeds, the three blade main rotor and the two blade
tail rotor, with the 10 % criterion applied:

| Rotor | Harmonic | Band |
| --- | --- | --- |
| main | 1/rev | 5.25 – 7.33 Hz |
| main | 2/rev | 10.50 – 14.67 Hz |
| main | 3/rev | 15.75 – 22.00 Hz |
| tail | 1/rev | 30.00 – 44.00 Hz |
| tail | 2/rev | 60.00 – 88.00 Hz |

Six admissible windows exist between the bands. The installation is estimated at **21.9 to
43.3 Hz** — the interval between the simply supported and the clamped idealisation of the frame
rails, which is the honest range a single degree of freedom model can give. That interval
crosses the 3/rev band and the tail rotor 1/rev band, and **no window is wide enough to contain
it**: the uncertainty of the estimate is wider than the gap between the harmonics. Raising the
first mode above the highest band would need 136 mm square rails of the declared wall
thickness, 8.8 kg of frame instead of 5.6 kg — 3.2 kg more against a kit budget with 1.4 kg
left. So the case is closed as a `LIMITATION` with an open item: it needs a modal analysis or a
ground vibration test on the first article, and possibly a damper, not a blind stiffness
increase.

**A traceability gap that the loads exposed.** The declared emergency landing factors (3.0 g up,
3.0 g down, 4.0 g forward, 4.0 g aft, 2.0 g lateral) are platform criteria, and the study runs
them as ultimate. They are not 14 CFR 27.561: that clause covers each occupant and the items of
mass *inside the cabin*, with factors of 4 g up / 16 g forward / 8 g sideward / 20 g down /
1.5 g rearward; 27.561(c) covers items of mass above and behind the cabin, and 27.561(d) the
structure in the fuel tank area. A belly installation is outside all three, so the factors are
declared data whose traceability has to be confirmed by the platform. Recorded as open item
OI-01 rather than dressed up as a citation.

**The hand calculation block was not the only reference: the clauses were checked.** 14 CFR
27.301 (prescribed loads are limit loads unless otherwise provided), 27.303 (factor of safety
1.5, and no factor where a condition is prescribed as ultimate), 27.305 (limit loads without
detrimental deformation, ultimate loads without failure), 27.337 (manoeuvre envelope +3.5 to
−1.0) and 27.561 (emergency landing) were read on the public text before being cited.

**Closure**

| Case | Status | What the evidence shows | What it does not |
| --- | --- | --- | --- |
| VER001 load transfer | `PASS` | seven cases, four fittings, reactions computed from the inertia force and the couple, against the declared hard point capability | the platform capability is declared data; the payload interface and the plate are not checked |
| VER002 factor of safety | `PASS` | the factor per case against the factor that case requires, and the stresses against the declared allowables | the allowables are declared handbook values (A-014); welds and the interface plate are not sized |
| VER011 resonance | `LIMITATION` | the excitation bands and the admissible windows, and the estimate with its uncertainty | the separation itself: a single degree of freedom model cannot establish it (OI-02) |

Model state: 38 requirements, 28 verification cases (`PASS` 11, `LIMITATION` 6, `FUTURE` 11),
15 declared assumptions, 93 layout checks, 44 load path checks, 127 tests. Validator: 0 errors,
10 warnings.

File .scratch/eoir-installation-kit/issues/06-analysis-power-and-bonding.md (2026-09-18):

# 06: Power budget and bonding

**What to build:** the electrical power budget and the protection coordination check, plus the bonding requirement recorded for the test that will close it.

**Blocked by:** 01, 02.

**Status:** resolved

- [x] Continuous and peak demand compared with the harness and protection sizing (SYS010)
- [x] Circuit protection coordinated with the platform distribution, with the load analysis entry identified (SYS011)
- [x] Voltage drop along the harness computed for the declared current and length
- [x] Bonding requirement (SYS013) kept FUTURE until a test article exists, with the limitation written down
- [x] Output committed under `evidence/` and referenced by VER006 and VER007
- [x] Matrix regenerated

## Answer

Closed on 2026-09-18.

**The numbers.** Payload demand 150 W continuous and 400 W peak at 28 VDC, over 2.4 m of
2.5 mm² copper:

| Quantity | Value | Limit | Margin |
| --- | --- | --- | --- |
| Continuous current | 5.36 A | 20 A (conductor ampacity) | +14.64 A |
| Continuous voltage drop | 0.180 V | 0.560 V (2 % of the bus) | +0.38 V |
| Peak voltage drop | 0.480 V | 1.120 V (4 %) | +0.64 V |
| Breaker rating | 20 A | 17.86 A required (1.25 × peak) | +2.14 A |
| Bus load after the installation | 2251 W | 3000 W | +749 W |

Five checks, all passing: `POWER-CONTINUOUS`, `POWER-PEAK`, `POWER-AMPACITY`, `POWER-BREAKER`,
`POWER-BUS`. `evidence/power/` holds `checks.json` and `report.md`.

**An open item found by the analysis, and kept open.** The declared payload inrush is 25 A,
above the 20 A breaker rating, and the breaker trip curve is not available in this study: the
coordination of the transient cannot be closed with the declared data. It is written into
`model/power.yaml` as an open item, it appears in the generated report, and it is the reason
`VER007` carries a `LIMITATION` instead of a `PASS` — either a curve with a suitable delay or a
higher rating with a larger conductor, and both are design changes to be taken deliberately.
The second open item is the load analysis entry itself, which belongs to the platform
document; this study computes the value to enter.

**Bonding stays open by design.** `VER009` remains `FUTURE` with the plan pointing at the
qualification ticket: the 2.5 mΩ limit is the declared design rule `A-008`, still open, and the
bonding path is declared in the layout, not measured. Nothing is promoted.

**Closure**

| Case | Status | What the evidence shows | What it does not |
| --- | --- | --- | --- |
| VER006 power budget | `PASS` | currents, voltage drop, ampacity, breaker sizing and bus load against the declared limits | the payload demand and the bus data are declared inputs |
| VER007 protection coordination | `LIMITATION` | steady and peak coordination, and the value for the load analysis entry | the transient: the trip curve is not available |

One `ASM-OPEN` warning is added (`SYS010` on the declared payload power demand); the existing
warnings stand.

Model state: 38 requirements, 28 verification cases (`PASS` 9, `LIMITATION` 5, `FUTURE` 14),
107 tests. Validator: 0 errors, 9 warnings.

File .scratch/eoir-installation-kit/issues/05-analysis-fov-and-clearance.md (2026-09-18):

# 05: Field of view and clearance analysis

**What to build:** the geometric analysis that shows the installation does not obstruct the payload field of view and that the minimum clearances are preserved in every operating configuration, as a script with its output committed as evidence.

**Blocked by:** 01, 02.

**Status:** resolved

- [x] Payload swept volume built from the declared field of view and envelope
- [x] Obstruction against the declared platform geometry, in every configuration of the kit
- [x] Minimum clearance measured and compared with the SYS009 value
- [x] Marginal configurations reported, not hidden
- [x] Output committed under `evidence/` and referenced by VER005
- [x] Matrix regenerated

## Answer

Closed on 2026-09-18.

**The analysis found a real conflict and the design was changed because of it.** The first
run put the existing belly antenna (`SM-04`, at x −100…100, y −490…−430, directly below the
gimbal) inside the swept sector: **229 of 301 rays obstructed, over 114 degrees of
elevation**. The antenna moved outboard and forward (x −520…−380, y −660…−600), out of the
sector and out of the removal corridor. The run that produced that failure is not in the
repository — the repository holds the corrected design and the analysis that proves it — but
the number is recorded here because it is the reason the layout changed.

**How the sector is built.** `model/layout.yaml` declares the gimbal centre, the head radius
(190 mm, from the payload envelope) and the sampling step (0.5°); the elevation range
(−120° to +30°) is read from the payload interface data, so no number is written twice. The
sector is sampled with one ray per step: 301 rays for the declared range.

**Three checks, and the marginal directions.**

| Check | Result |
| --- | --- |
| `FOV-OBSTRUCTION` | 0 of 301 rays obstructed, sector −120° to +30° clear |
| `FOV-SKIN` | highest ray 325 mm below the platform skin (requirement 25 mm) |
| `FOV-CLEARANCE` | tightest direction 0.0°, nearest element `SM-05` (lower fuselage step): **30 mm against the 25 mm requirement** |

The report lists the clearance direction by direction and has a *marginal directions*
section: the horizontal directions near 0° keep 30 mm, inside twice the requirement, and they
are named instead of averaged into a comfortable number. `evidence/clearance/` holds
`checks.json`, `report.md` and `sweep.svg` (the sector and the rays over the side view, with
obstructed rays in red and marginal rays in orange).

**Configurations.** The sector exists only with the payload installed; with the payload
removed there is nothing to sweep, and that configuration is bounded by the removal-corridor
check in the layout evidence. The report says so instead of pretending to analyse an empty
installation.

**Closure**

| Case | Status | What the evidence shows | What it does not |
| --- | --- | --- | --- |
| VER005 field of view and clearance | `PASS` | the swept sector is clear and the clearance is met in the declared geometry | the platform geometry is a declared 2D envelope, not a CAD model: the analysis bounds the clearance, it does not replace a 3D check |

Two `ASM-OPEN` warnings appear (`SYS008` on the declared field of view, `SYS009` on the
declared clearance), by design: the analysis is only as good as the declared envelope.

Model state: 38 requirements, 28 verification cases (`PASS` 8, `LIMITATION` 4, `FUTURE` 16),
90 layout checks, 96 tests. Validator: 0 errors, 8 warnings.

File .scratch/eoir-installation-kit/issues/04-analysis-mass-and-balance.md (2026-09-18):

# 04: Mass and balance analysis

**What to build:** the analysis that produces the kit mass budget and the platform weight and balance impact, as a script with its output committed as the artifact of the verification cases it closes.

**Blocked by:** 01, 02.

**Status:** resolved

- [x] Component masses are declared per element and summarised by the script, not typed into a table
- [x] Kit mass compared with the SYS005 target, with the margin stated
- [x] Platform centre of gravity computed for the loadable configurations, compared with the SYS007 range
- [x] Payload envelope check (SYS006) using the declared interface data
- [x] Output committed under `evidence/` and referenced by the artifact field of VER003 and VER004
- [x] The three verification cases move out of `FUTURE` with the status the result supports

## Answer

Closed on 2026-09-18.

**One declaration, one computation.** `model/mass.yaml` declares one mass per architecture
component (twelve entries, `source: DECLARED`, each with a note on where the estimate comes
from), the two installation stations and four loadable configurations. The platform data
(empty mass, empty CG, certified CG range, MTOW) and the payload data (mass, CG envelope) are
read from the interface control files, so those numbers live in exactly one place. The new
rule `MASS-COVERAGE` fails the build when a component has no declared mass, when a mass entry
names a component that does not exist, when a mass is not positive, or when the source is not
`DECLARED` or `DERIVED`.

**The result, as a bound rather than a nominal case.** The four configurations use the payload
CG envelope limits and the 5 % component mass tolerance on purpose, so the table is a worst
case:

| Configuration | Kit (kg) | Total (kg) | Platform CG (mm) | Closest limit |
| --- | --- | --- | --- | --- |
| CFG-01 forward payload CG, kit at +5 % | 14.28 | 1409.3 | 2987.0 | +87.0 mm (forward) |
| CFG-02 nominal | 13.60 | 1408.6 | 2992.1 | +92.1 mm |
| CFG-03 aft payload CG | 13.60 | 1408.6 | 2996.9 | +153.1 mm |
| CFG-04 payload removed | 14.28 | 1364.3 | 3013.0 | +113.0 mm |

Kit mass 13.60 kg against the 15 kg target (1.40 kg of margin, 9.3 %). Sixteen checks, all
passing: `MASS-KIT`, `MASS-PAYLOAD`, `MASS-BALANCE`, `MASS-MTOW` on every configuration.

**Evidence.** `evidence/mass/checks.json` (machine readable, with the component list and every
configuration) and `evidence/mass/report.md` (inputs, configurations, checks, component
masses). CI runs `python -m tools.mass --check`, so the committed evidence cannot drift from
the model.

**Verification cases closed**

| Case | Status | What the evidence shows | What it does not |
| --- | --- | --- | --- |
| VER003 mass and balance | `PASS` | kit mass against the target and the platform CG against the certified range, four configurations | any weighed mass: every figure is a declared estimate |
| VER004 payload envelope | `PASS` | the payload is carried at its declared mass and at both CG envelope limits | a heavier payload or one outside the envelope, which is a design change |

Three `ASM-OPEN` warnings appear on `SYS005`, `SYS006` and `SYS007`: the whole analysis rests
on the declared payload and platform data (`A-001`, `A-002`, `A-004`), and the warnings say so.

Model state: 38 requirements, 28 verification cases (`PASS` 7, `LIMITATION` 4, `FUTURE` 17),
15 rules, 85 tests. Validator: 0 errors, 6 warnings.

**Refactor carried out with the ticket**: the result structure shared by the analysis tools
(`Finding`, the margin convention, the table renderer) moved into `tools/analysis.py`, so the
layout, mass and next analyses produce the same shape of evidence.

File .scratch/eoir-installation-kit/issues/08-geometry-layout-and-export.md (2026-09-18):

# 08: Geometry layout and export

**What to build:** the parametric layout of the kit — interface frame, attachment fittings, payload plate, harness routing — with automated checks of clearance, access and fit, and a neutral export for review.

**Blocked by:** 03.

**Status:** resolved

- [x] Layout driven by parameters, with one source of truth for dimensions
- [x] Automated checks: clearances, payload removal path, connector access, fitting edge distances
- [x] A check that fails stops the build and says which constraint was violated
- [x] Neutral export (STEP or DXF) and figures generated by script
- [x] Interface control data for the payload plate recorded
- [x] Output committed under `evidence/` and referenced by VER008 and VER013
- [x] Matrix regenerated

## Answer

Closed on 2026-09-18.

**The layout is one file.** `model/layout.yaml` at revision A is the single source of truth for
every dimension: a two-view 2D envelope model in millimetres (side view and bottom view) with
rectangles, circles and orthogonal harness paths, plus the declared design rules and the
interface references the layout has to agree with. The 2D simplification is declared in the
file and in the README, not hidden.

**Twelve checks, 89 assertions.** `tools/layout.py` runs `REMOVAL-CORRIDOR`,
`CONNECTOR-ACCESS`, `FITTING-EDGE-DISTANCE`, `HOLE-PITCH`, `FASTENER-LOCKING`,
`INSPECTION-ACCESS`, `HARNESS-ORTHOGONAL`, `BEND-RADIUS`, `CLAMP-ON-PATH`, `CLAMP-SPACING`,
`HARNESS-CLEARANCE` and `ICD-CONSISTENCY`. Each finding carries the check identifier, the
subject, the measured value, the limit and the margin, so a failure names the violated
constraint instead of reporting a feeling. The tool exits non-zero on the first failing run
and prints the failing subjects.

The checks earned their place immediately: the first run failed on four clamp spacings
(300 mm, 210 mm, 240 mm and 270 mm against a 200 mm rule) and on one non-orthogonal harness
segment in the declared data. Both were layout errors, both were fixed in the layout, not in
the checks.

**Evidence.** `evidence/layout/` holds four generated files: `checks.json` (machine
readable), `report.md` (the table with values and margins), `layout.svg` (the two views) and
`layout.dxf` (a DXF R12 ASCII export with both views, one layer per element class). CI runs
`python -m tools.layout --check`, so the committed evidence cannot differ from the model.

**Verification cases closed at the design-definition level**

| Case | Status | What the evidence shows | What it does not |
| --- | --- | --- | --- |
| VER008 harness routing and pinout | `PASS` | routing, clamping, bend radius, connector access and the interface references agree with the declared rules and the ICD | the installed harness on an article |
| VER013 maintainability | `LIMITATION` | removal corridor free and inspection access preserved | the 30-minute, two-maintainer target without a first article |
| VER019 fastener locking | `PASS` | every fastener declares two independent locking devices | procurement and installation |
| VER021 inspection provisions | `PASS` | the inspection zones stay clear of the payload footprint | access with the payload installed on the platform |
| VER023 harness installation rules | `PASS` | clearance to hot zones and moving parts, clamp spacing, bend radius | clamp installation on the structure |

Three `ASM-OPEN` warnings appear, by design: the evidence rests on the harness rules (`A-012`,
used by `SYS030`/`SYS031`) and on the payload video link (`A-007`, used by `SYS012`), both still
open.

Model state: 38 requirements, 28 verification cases, 12 components, 13 assumptions, 10 rules,
89 layout checks, 55 tests. Validator: 0 errors, 3 warnings.

**One mismatch found and not hidden**: the platform ICD declares attachment hard points 900 mm
apart longitudinally and 300 mm laterally, while the first draft of the layout placed them
340 mm apart. The layout was rebuilt on the declared hard points, and the `ICD-CONSISTENCY`
check now fails if either document drifts.

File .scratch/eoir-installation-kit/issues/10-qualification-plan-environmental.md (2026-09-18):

# 10: Environmental qualification plan

**What to build:** the environmental qualification plan of the installation: DO-160G sections and categories selected per installation zone, the test matrix, the resonance and EMC assessment approach, and the platform protection preservation check against the protection plan.

**Blocked by:** 03, 09.

**Status:** resolved

- [x] Installation zones defined and the applicable DO-160G sections selected per zone, with the category for each
- [x] Category selection argued (temperature and altitude, vibration, humidity, salt spray, power input, RF emission and susceptibility) and every value traced to the declared zone
- [x] EMC approach stated: what is assessed by analysis and what requires a test on an article
- [x] Lightning and HIRF preservation check against the platform protection plan
- [x] What cannot be done without a test article declared as a limitation, not as an open item
- [x] Matrix regenerated; plan committed under `docs/`

## Answer

Closed on 2026-09-18. `model/qualification.yaml` declares the zones, the sections, the
categories, the methods, the articles and the protection means; `tools/qualification.py` checks
the plan and writes it into `docs/qualification-plan.md`, which is the compliance document
TP-001 — the register now points at it and the validator fails if it points anywhere else. 46
checks, all passing.

**The zones.** Three, taken from the layout rather than assumed: the external belly bay (Z-01,
ten components, everything below the skin line), the unpressurised fuselage interior with the
protection assembly and the mission system panel (Z-02, four components, from the platform
interface data), and a zone for what is not installed (Z-03, the documentation set, exempt from
qualification with the reason written down). Every architecture component is placed in a zone,
and that is checked.

**The sections.** 24 entries covering all 26 sections of the standard except the ones that do
not reach this installation, plus a functional test for the ARINC 429 control link and the
video link. The check that matters: **every DO-160G section a requirement cites appears in the
plan**, computed from the requirement references themselves — sections 4, 6, 8, 11, 12, 13, 14,
16, 20, 21 come from SYS014, SYS016, SYS033 and SYS034, and the plan answers all ten.

**What is selected, and what is not.** This is the honest part of the ticket. The standard is
not in this repository, so a category is written down only where a declared input of this study
and a public statement about the standard fix it:

| Selection | Why it is defensible |
| --- | --- |
| Section 4, family D for the belly bay | The bay is unpressurised external mounting, which is the D family; the declared payload range (−40/+55 operating, −55/+85 storage) sits inside the −55/+85 the section spans |
| Section 10, category T | T is externally mounted equipment subject to direct rainfall and washing, which is what the bay is |
| Section 16, category Z | The installation is 28 Vdc equipment, and Z is the 28 Vdc category for all other systems and is accepted in lieu of A or B, so it covers the platform whether the dc comes from a transformer-rectifier unit or from engine-driven generators with a battery on the bus |
| Section 8, family R or U | The robust categories apply to rotary wing, tested sine-on-random; the curve still comes from the table of categorisation by aircraft type and equipment location |
| Sections 7.3, 9, 10 for the interior bay, 12, 14, 23 and 24 outside the belly bay | The section does not reach that zone, and the reason is written next to it |

Thirty zone selections stay **open on a named input**: the compartment map, the design altitude,
the ramp rate, the HIRF and lightning environment, the radio compatibility limits, the fluid
list, the bus transient data, the icing approval, the platform magnetic survey. None of them is
filled with a plausible letter.

**Three entries are closed now, by analysis or inspection**, not by test: crash safety (7.3),
which the published statement limits to places where detached equipment can hurt somebody, so
the crash inertia loads are carried by the structural analysis of ticket 07 instead; explosive
atmosphere (9), which needs the platform to confirm that no fuel vapour zone reaches the
installation; and fungus (13), assessed by inspecting the declared materials, which are metals.

**Two findings the last two miles of work produced.**

The first: **the ticket-06 and 07 edits had left two evidence records for four verification
cases** (VER001, VER002, VER006, VER007). The loader kept the last one silently, so every check
stayed green while the register contradicted itself. The duplicates are gone, `tools/model.py`
now exposes them and `tools/rules.py` reports `EVIDENCE-DUPLICATE`, with a test that fails on a
model with two records for one case. That is a defect this study introduced and then caught by
checking its own register, and it is worth more than the plan itself.

The second: **`CONTEXT.md` had not been updated by ticket 07**, because a two-part edit of that
file failed as a whole and the failure was missed. The load path vocabulary and the
qualification vocabulary are in it now.

The third, and the one that cost five red pipelines: **the evidence leaked the platform's path
separator**. The success message of the plan check interpolated the `Path` object, so it read
`docs\qualification-plan.md` on the machine that generated the evidence and
`docs/qualification-plan.md` on the runner, and the freshness check compared one line of JSON
that differed by one character. The comparison next to it had been normalised; the message had
not. The same latent landmine sat in a layout check message and is fixed with it.

It took that long to find because **the log of a public repository needs a login**. What worked
was making the pipeline report a freshness failure as an annotation: the changed files, the
difference and the interpreter versions, which are readable without one. That script is now in
`.github/scripts/check_freshness.sh` and the step that needed it reports through it. The lesson
is not the path separator: it is that a check whose failure cannot be read is not a check.

The second finding of the same kind was a real order dependency, even if it turned out not to be
the cause: **the citation map was built in the order Doorstop reads the requirements in**, which
differs between file systems. `cited_sections` now walks them in identifier order and names
every requirement that cites a section, and a test reverses the order to prove the result does
not move. `tools/traceability.py` had sorted its requirements all along; the new tool had not.

Model state: 38 requirements, 28 verification cases (`PASS` 13, `LIMITATION` 10, `FUTURE` 5),
15 declared assumptions, 46 qualification checks, 150 tests. Validator: 0 errors, 12 warnings.

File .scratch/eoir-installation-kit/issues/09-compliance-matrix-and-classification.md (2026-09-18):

# 09: Compliance matrix and change classification

**What to build:** the compliance frame of the installation — change classification under EASA Part 21 Subpart D, approval route, compliance matrix with the verification method per requirement, list of the documents that will carry the evidence, and the instructions for continued airworthiness outline.

**Blocked by:** 02, 03.

**Status:** resolved

- [x] Change classification (minor or major, 21.A.91) argued with the criteria, and the approval route recorded (21.A.95 / 21.A.97)
- [x] Compliance matrix generated from the model: requirement, method, document, status
- [x] Document list (drawings, analyses, test plans, ICA) with the requirement each one satisfies
- [x] Instructions for continued airworthiness outlined (14 CFR 27.1529 and Appendix A)
- [x] Every requirement of the study appears in the matrix exactly once
- [x] Matrix regenerated; compliance matrix committed under `docs/`

## Answer

Closed on 2026-09-18.

**The classification is argued, not asserted.** `model/compliance.yaml` records the
classification as `OPEN` with the outcome `MAJOR` proposed, on nine appreciable-effect
criteria: weight and balance, structural strength, electrical system, avionics and data
interfaces, environmental protection, operating limitations and flight manual, instructions
for continued airworthiness (all `YES`), flight characteristics and safety assessment (both
`OPEN`, with the reason). The approval route is 21.A.97 unless the design organisation
concludes a minor change and approves it under 21.A.95; the privileges relied on are
21.A.263(c)(1) classification, (c)(2) minor changes and (c)(5)/(8) major change under
privilege. Three open items are recorded, including the platform procedure.

**The register assigns every requirement to exactly one document.** Thirteen documents:
two drawings (`DWG-001`, `DWG-002`), six analyses (`AN-001`–`AN-006`), two test documents
(`TP-001`, `TP-002`), the ICA (`ICA-001`), the generated compliance checklist (`CS-001`) and
the flight manual supplement (`FMS-001`). The `COMPLIANCE-COVERAGE` rule fails the build when
a requirement has no document or two, and `COMPLIANCE-FILE` fails when a document declares a
file that does not exist. The matrix is generated by `tools/compliance.py` into
`docs/compliance-matrix.md` (requirement, source, verification cases, method, document,
document state, evidence state) and CI checks that it is current.

**The ICA is outlined, not invented.** `docs/ica.md` follows the structure of 14 CFR 27.1529
and Appendix A — general, limitations, servicing, scheduled inspections, wear items,
structural repair, troubleshooting, parts list — with the inspection table and the open items
(intervals, torque values, airworthiness limitations) written down instead of filled with
plausible numbers.

**Verification cases after the ticket**

| Case | Status | Why |
| --- | --- | --- |
| VER014 certification and compliance data | `PASS` | classification recorded with criteria, design assurance cited, every requirement covered once |
| VER015 instructions for continued airworthiness | `LIMITATION` | outline complete; intervals, torque values and limitations open |
| VER027 configuration control and part identification | `LIMITATION` | register and revisions defined at study level; no approved DOA procedure |
| VER028 loading information and flight manual | `LIMITATION` | document planned; no flight manual supplement exists without the platform |

The three structural deliverables that were planned here — material design values (`VER018`),
corrosion protection (`VER020`) and critical parts (`VER022`) — moved to the structural
analysis ticket (07), which is where they are produced.

Model state: 38 requirements, 28 verification cases (`PASS` 5, `LIMITATION` 4, `FUTURE` 19),
13 documents, 14 rules, 71 tests. Validator: 0 errors, 3 warnings.

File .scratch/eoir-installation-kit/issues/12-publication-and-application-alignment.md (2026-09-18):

# 12: Publication and application alignment

**What to build:** the published front page of the study and the alignment of the application texts — README of the repository, figures and index of the documentation, description of the repository, and the CV, letter and messages that cite it.

**Blocked by:** 11.

**Status:** ready-for-agent

- [ ] README opening page: what the study is, what it is not, what is verified, what is not
- [ ] Figures and documentation index in the README
- [ ] Repository description and topics set on the hosting platform
- [ ] Application texts cite the repository exactly as it is: models, requirements, traceability, validator
- [ ] Every claim in the application texts has a file in the repository behind it
- [ ] Link verified in anonymous browsing

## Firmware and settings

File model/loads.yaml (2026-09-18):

# Load path and strength model of the installation kit.
#
# What is declared here: the material allowables, the structural idealisation
# (frame and fitting sections, support conditions) and the design rules of the
# strength analysis. What is read from the rest of the model, so that it is
# declared once: the payload mass and centre of gravity (interface control file),
# the platform accelerations and attachment capability (interface control file),
# the kit mass (model/mass.yaml), the attachment geometry (model/layout.yaml) and
# the available clearance (the field of view analysis).
#
# The load cases are derived by tools/loads.py from the declared accelerations:
# they are not listed here, so a change in the platform data changes the analysis
# instead of leaving a stale case behind.
#
# Basis vocabulary:
#   limit      — the prescribed condition is a limit load; the factor of safety
#                of 14 CFR 27.303 is applied to reach the ultimate load;
#   ultimate   — the prescribed condition is already an ultimate load, and
#                27.303 applies no further factor to it.

revision: A
date: 2026-09-18
units: mm, N, MPa

declared_rules:
  factor_of_safety: 1.5                # SYS002, 14 CFR 27.303
  bearing_allowable_ratio: 1.5         # bearing allowable = ratio x Fty — declared joint rule (A-014)
  shear_allowable_ratio: 0.6           # fastener ultimate shear = ratio x fastener Ftu — declared rule (A-014)
  bolt_shear_plane: threaded           # shear taken in the threaded portion: conservative (A-014)
  frame_coefficient_simply_supported: 48  # rails as a beam on two supports: k = 48 E I / L^3, the soft idealisation
  frame_coefficient_clamped: 192           # rails clamped at the fittings: k = 192 E I / L^3, the stiff idealisation
  fitting_cantilever_factor: 3.0       # fitting bracket treated as a clamped cantilever: k = 3 E I / L^3
  fitting_stress_rule: >-              # declared combination rule for the fitting critical section
    bending from the direct share over the declared lever and axial stress from
    the couple are added, because they act on the same face; the in-plane shear
    enters a von Mises combination: sqrt((sigma_b + sigma_a)^2 + 3 tau^2).
  modal_mass_frame_share: 0.5          # fraction of the frame mass that follows the first mode
  separation_pct: 10                   # SYS015: no resonance within 10 % of the excitation frequencies
  excitation_harmonics:                # harmonics considered, per rotor
    main: [1, 2, 3]                    # 1/rev (balance), 2/rev, 3/rev (blade passage, three blades)
    tail: [1, 2]                       # 1/rev, 2/rev (blade passage, two blades)
  frequency_ceiling_hz: 200            # above this the analysis stops looking for admissible windows

# Declared structural idealisation (A-014). The 2D layout model carries no
# section, so the sections are declared here and the lengths come from
# model/layout.yaml.
sections:
  frame_rail:
    profile: 40 x 40 x 3 square tube, extruded
    height_mm: 40
    width_mm: 40
    wall_mm: 3
    count: 2                           # the two longitudinal rails BL-01, BL-02
    material: MAT-01
  fitting:
    width_mm: 120                      # the fitting rectangle, model/layout.yaml
    thickness_mm: 10                   # A-013 requires at least the fastener diameter
    effective_lever_mm: 40             # bending length from the bolt pattern to the frame rail
    count: 4
    material: MAT-01
    fasteners_per_fitting: 2

materials:
  - id: MAT-01
    name: Aluminium 6082-T6, extruded tube and plate
    source: DECLARED
    note: >-
      Typical minimum values for the temper (Rm 310 MPa, Rp0.2 260 MPa, E 70 GPa).
      They are declared inputs of the study: the material certificate and the
      design allowables of the delivered part have to confirm them (A-014).
    ftu_mpa: 310
    fty_mpa: 260
    e_mpa: 70000
    density_kg_m3: 2700
  - id: MAT-02
    name: M8 fastener, corrosion-resistant steel, A4-80
    source: DECLARED
    note: >-
      Declared ultimate tensile strength and 0.2 % proof strength of the grade
      (ISO 3506-1 for A4-80) and the thread stress area of an M8 coarse thread.
      Shear is taken in the threaded portion, which is the conservative shear
      plane (A-014).
    ftu_mpa: 800
    fty_mpa: 600
    thread_stress_area_mm2: 36.6
    diameter_mm: 8
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

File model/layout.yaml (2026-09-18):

# Layout definition of the installation kit — the single source of truth for
# every dimension of the study.
#
# This is a two-view 2D envelope model (side view and bottom view): rectangles,
# circles and orthogonal harness paths. It is not a 3D CAD model; that
# simplification is declared, not hidden. Everything published — the checks, the
# report, the SVG figure and the DXF export — is generated from this file by
# tools/layout.py, so no dimension is typed twice.
#
# Coordinates are millimetres. Bottom view: x longitudinal (forward positive),
# y lateral (right positive). Side view: x longitudinal, y vertical (up
# positive), the platform skin at y = 0.

revision: A
date: 2026-09-18
units: mm

# Design rules of the study. They are declared inputs, like an assumption: they
# are not yet confirmed against a platform installation standard.
declared_rules:
  edge_distance_factor: 2.0        # multiple of the fastener diameter, to the fitting edge (A-013)
  hole_pitch_factor: 3.0           # multiple of the fastener diameter, between holes (A-013)
  connector_access_radius: 60      # free radius around a payload connector (A-012)
  inspection_access_radius: 80     # free radius around a fitting (SYS019, SYS028)
  harness_clearance: 50            # from hot zones and moving parts (A-012)
  clamp_spacing_max: 200           # between consecutive clamps (A-012)
  bend_radius_factor: 5.0          # multiple of the cable outside diameter (A-012)
  minimum_clearance_mm: 25         # SYS009, assumption A-005

side_view:
  platform_skin_y: 0
  frame_members:
    - { id: SM-01, name: Forward attachment structure, rect: [-520, -260, -380, -40] }
    - { id: SM-02, name: Aft attachment structure, rect: [380, -260, 520, -40] }
    - { id: SM-03, name: Belly beam, rect: [-60, -120, 60, -40] }
    - { id: SM-04, name: Belly antenna, relocated outboard of the swept volume, rect: [-520, -660, -380, -600] }
    - { id: SM-05, name: Lower fuselage step, right side, rect: [220, -450, 260, -390] }
  payload_envelope:
    id: PE-01
    rect: [-190, -480, 190, -40]
  removal_corridor:
    id: RC-01
    rect: [-260, -980, 260, -500]
  # The rotating head sweeps a sector around the gimbal axis. head_radius_mm is
  # the distance from the gimbal centre to the outer surface of the rotating
  # head, taken from the payload envelope. The elevation range is read from the
  # payload interface data by tools/clearance.py; the sector is bounded by
  # sampling one ray every ray_step_deg.
  field_of_view:
    gimbal_centre: [0, -420]
    head_radius_mm: 190
    ray_step_deg: 0.5
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

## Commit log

2026-09-18 feat: model, validator and traceability matrix (first published slice)
    Model-based system engineering study of an EO/IR payload installation kit
    for a light helicopter (CS-27 class) and a tactical UAV.
    - 23 system requirements (Doorstop), each with a source: standard clause or
    declared assumption; no requirement without a source
    - 16 verification cases linked to their requirements, all FUTURE and each
    pointing at the ticket that will produce its evidence
    - architecture model: 9 functions, 11 components, 8 interfaces, externals
    - tools/rules.py: one rule identifier per failure mode, enforced in CI
    - docs/traceability.md generated from the model and checked for freshness
    - 29 tests: one f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
2026-09-18 feat(model): complete requirement coverage (ticket 02)
    Fifteen requirements (SYS024-SYS038) close the gaps found against 14 CFR Part 27
    Subpart D and the DO-160G section list: structural design rules (fitting factor
    1.15, material design values, fastener locking, protection of structure,
    inspection provisions, critical parts), harness routing and protection, connector
    retention, circuit protection access, fluids and sand/dust/fungus, lightning and
    static protection, configuration control, loading information and part
    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
2026-09-18 feat(architecture): interface control data as files, generated architecture document (ticket 03)
    - model/interfaces/icd_payload.yaml and icd_platform.yaml hold the declared
    interface values; assumptions point at them with data_file
    - new rule ASM-FILE rejects a pointer to data that is not in the repository
    - tools/diagram.py generates docs/architecture.md: Mermaid diagram of the
    components and the external boundary plus the allocation tables
    - CI checks that the architecture document is current, like the matrix
    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
2026-09-18 feat(layout): parametric layout, 12 geometric checks, DXF and SVG evidence (ticket 08)
    - model/layout.yaml is the single source of truth for every dimension: a
    two-view 2D envelope model with declared design rules and interface refs
    - tools/layout.py runs 89 assertions over 12 checks (removal corridor,
    connector access, edge distance, hole pitch, fastener locking, inspection
    access, orthogonality, bend radius, clamp position and spacing, clearance to
    hot zones and moving parts, ICD consistency)
    - evidence/layout/ generated: checks.json, report.md, layout.svg, layout.dxf
    (R12 ASCII, both views, one layer per element class); CI verifies freshness
    - five verification cases closed at t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
    [layout.dxf]
2026-09-18 feat(mass): component mass model, balance analysis and evidence (ticket 04)
    - model/mass.yaml declares one mass per component, the installation stations and
    four loadable configurations; platform and payload data are read from the ICDs
    - tools/mass.py computes the kit mass budget and the platform CG per
    configuration and writes evidence/mass/ (checks.json, report.md); CI verifies
    freshness
    - new rule MASS-COVERAGE: no component without a mass, no mass without a
    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
2026-09-18 feat(clearance): field of view and clearance analysis (ticket 05)
    - model/layout.yaml declares the swept sector geometry (gimbal, head radius,
    sampling step) and the minimum clearance rule; the elevation range is read
    from the payload interface data
    - tools/clearance.py samples the sector with 301 rays and checks obstruction,
    skin clearance and minimum clearance; writes evidence/clearance/ (checks.json,
    report.md, sweep.svg) with the clearance direction by direction and a marginal
    directions section
    - the analysis found the belly antenna inside the sector (229 of 301 rays
    obstructed over 114 degrees): the antenna moved outboard, out of the sector and
    out of the removal corridor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
    [layout.dxf]
2026-09-18 feat(power): electrical budget, protection coordination and open items (ticket 06)
    - model/power.yaml declares the kit conductors, the protection device, the design
    rules and the open items; the payload demand and bus data come from the ICDs
    - tools/power.py computes currents, voltage drop, ampacity, breaker sizing and
    bus load, and writes evidence/power/ (checks.json, report.md); CI verifies
    - the analysis found that the declared 25 A inrush exceeds the 20 A breaker
    rating and the trip curve is not available: the item is reported and it is the
    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
2026-09-18 feat(loads): load path, strength analysis and the resonance estimate (ticket 07)
    - model/loads.yaml declares the allowables, the structural idealisation and the
    design rules; the masses, accelerations, attachment geometry and clearance come
    from the rest of the model, and the load cases are derived, not listed
    - tools/loads.py runs seven cases through the load path and writes
    evidence/loads/ (checks.json, report.md, 44 checks); CI verifies freshness
    - the attachment points did not match the platform provisions: the aft fittings
    were at 140 and 170 mm instead of mirrored 150 mm. Fixed in the layout, and
    ATTACHMENT-SPACING and ATTACHMENT-PATTERN now check it (93 layout checks)
    - the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
    [layout.dxf]
2026-09-18 fix(evidence): four verification cases carried two records each
    The ticket 06 and 07 edits added the new record before the existing one instead
    of replacing it, so VER001, VER002, VER006 and VER007 each had a stale FUTURE
    record next to the real one. The loader kept the last silently, which is why
    every check stayed green while the register contradicted itself.
    tools/model.py now exposes the duplicates and tools/rules.py reports them as
    EVIDENCE-DUPLICATE, with a test that fails on a model with two records for one
    case. The register states one state per case again.
2026-09-18 fix(qualification): the citation map no longer depends on the file system order
    The check on the CI runner failed and the one on the machine that generated the
    evidence passed: cited_sections built the map in the order Doorstop reads the
    requirement directory, which differs between file systems, so section 21 was
    attributed to SYS014 here and to SYS016 there and the freshness check saw a
    different file.
    - cited_sections walks the requirements in identifier order and names every
    requirement that cites a section, not just the first one it meets
    - a test reverses the requirement order and asserts the map does not move
    - tools/traceability.py had sorted its requirements all along; this tool h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
